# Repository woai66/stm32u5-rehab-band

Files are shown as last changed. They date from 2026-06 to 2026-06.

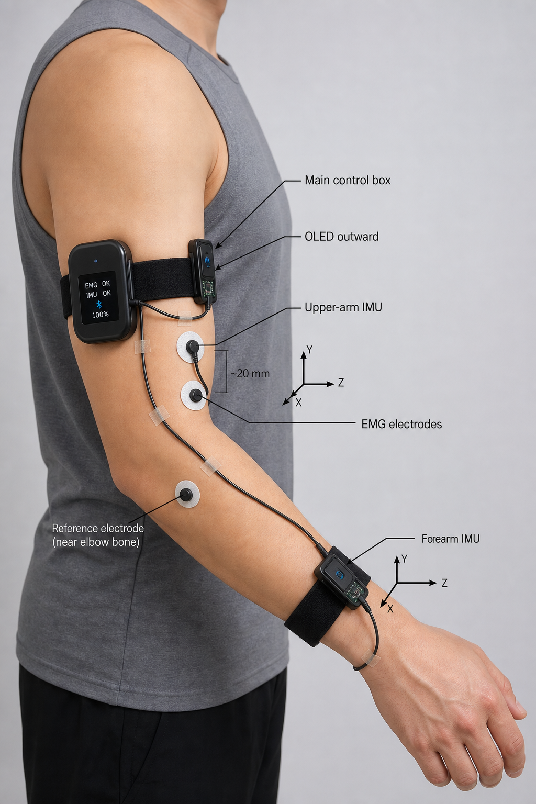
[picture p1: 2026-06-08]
备赛/1.png

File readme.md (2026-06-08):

《基于 STM32U575 的脑卒中上肢康复评估系统与 AI 动作识别优化》
STM32 嵌入式平台（NUCLEO-U575/NUCLEO-F401RE）+ Edge Impulse AI + FreeRTOS
本作品面向脑卒中患者上肢运动康复需求，基于 STM32U575/F401RE 双主控芯片构建智能康复臂带系统，创新采用上臂 + 手腕双 6 轴 IMU 传感器方案，通过 Madgwick AHRS 姿态融合算法实现肘关节角度（0°-180°）精确测量，结合轻量化 CNN 模型（<50KB）完成 6 类核心康复动作（前臂转动、肘关节弯曲等）的本地 AI 识别（准确率> 90%）。系统设计了 "完成度 ×60%+ 平稳度 ×30%+ 频率 ×10%" 的量化评分体系，搭配 TFT+OLED 双屏交互、语音播报及蓝牙 App 数据同步功能，可实时反馈康复动作质量（评分 < 60% 振动提醒、>80% 语音鼓励）。硬件端基于 FreeRTOS 实现多任务调度（传感器采集 100Hz、AI 推理 10Hz），整体成本控制在 2119 元，续航达 6 小时，为脑卒中患者提供低成本、高精度、智能化的上肢康复评估解决方案。

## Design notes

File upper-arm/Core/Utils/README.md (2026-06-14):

# Core/Utils

本目录用于放置项目内可复用的轻量工具函数，避免在 IMU、EMG、评分和显示逻辑中重复实现基础算法。

当前包含：

- `Rehab_ClampFloat` / `Rehab_ClampInt32`：限幅。
- `Rehab_MapFloat`：线性映射。
- `Rehab_DeadbandFloat`：死区处理。
- `Rehab_FirstOrderFilter`：一阶低通滤波。
- `Rehab_MovingAverage`：滑动平均。
- `Rehab_RmsFloat`：RMS 计算。

建议只放无业务含义的通用函数。具体的肘关节角度、动作识别、肌电参与度等逻辑仍放在各自模块中。

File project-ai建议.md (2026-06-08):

 方案A：入门级（推荐） ⭐⭐⭐

  核心思路

  简化方向：保留医疗场景 + 去掉云平台 + 算法降级

  项目名称：智能康复手表 —— 脑卒中患者上肢运动评估

  硬件配置（简化版）

  STM32U575 (NUCLEO开发板即可)
      ↓
  LSM6DSV16X (6轴加速度+陀螺仪) ← 只用1个传感器
      ↓
  NUCLEO自带的屏幕显示实时数据
      ↓
  蓝牙模块连接手机App
      ↓
  250mAh锂电池 (续航3-5天)

  不做的事：
  - ❌ 自制PCB（用开发板）
  - ❌ 5个传感器（只用6轴）
  - ❌ 云平台/医生Dashboard
  - ❌ 医疗规范认证文件
  - ❌ 复杂的AI模型

  要做的事：
  - ✅ 康复动作识别（3-5个标准动作）
  - ✅ 简单App展示数据
  - ✅ 每日训练进度记录
  - ✅ 工程化（自制PCB or 功能完整的开发板）

  核心创新点（3个）

  创新1：康复动作自动识别
  使用 STM32CubeAI 部署轻量CNN（<50KB）

  输入：加速度序列
  输出：[标准握拳, 前臂转动, 手臂外展, 步行, ...]

  模型训练：
    用开源数据集 + 自己录制的动作视频（20份）
    → 用 Edge Impulse 或 TensorFlow Lite 训练
    → 导出到MCU（完全本地推理）

  创新2：康复进度量化
  每次动作评分：
  - 完成度 (0-100%)：动作幅度是否达到标准
  - 平稳度 (0-100%)：运动轨迹是否平稳
  - 频率 (次/分)：运动速度

  总分 = 完成度*60% + 平稳度*30% + 频率*10%

  每日汇总 → 显示周趋势图

  创新3：智能反馈
  如果动作评分<60% → 振动提醒
  显示提示："前臂外展不足，请继续加大幅度"

  患者通过改进 → 评分逐渐提高 → 游戏化体验

  技术难度评估

  ┌─────────────────┬──────┬────────────────────────────────────────────┐
  │     技术点      │ 难度 │                    说明                    │
  ├─────────────────┼──────┼────────────────────────────────────────────┤
  │ STM32基础开发   │ ⭐   │ 用NUCLEO开发板降低难度                     │
  ├─────────────────┼──────┼────────────────────────────────────────────┤
  │ 6轴传感器融合   │ ⭐⭐ │ 直接用ST提供的库函数                       │
  ├─────────────────┼──────┼────────────────────────────────────────────┤
  │ 轻量CNN部署     │ ⭐⭐ │ Edge Impulse界面操作（不需要深度学习基础） │
  ├─────────────────┼──────┼────────────────────────────────────────────┤
  │ 蓝牙通信        │ ⭐⭐ │ 用STM32Cube提供的BLE Stack                 │
  ├─────────────────┼──────┼────────────────────────────────────────────┤
  │ Flutter App开发 │ ⭐⭐ │ 简单UI（就是显示数字和曲线图）             │
  ├─────────────────┼──────┼────────────────────────────────────────────┤
  │ 功耗优化        │ ⭐   │ 基础低功耗模式配置                         │
  └─────────────────┴──────┴────────────────────────────────────────────┘

  总体难度：⭐⭐⭐ (高中水平可做)

  工作量估算

  - 硬件集成：1-2周
  - 固件开发：3-4周
  - AI模型训练：2-3周
  - App开发：2-3周
  - 测试优化：1-2周
  - 总耗时：4-6个月 ✓

  预期获奖等级

  - 省赛：一等奖 (80%概率)
  - 国赛：三等奖以上 (60%概率)

---
  方案B：中级 ⭐⭐⭐⭐

  在方案A基础上增加

  增加1：多传感器融合
  LSM6DSV16X (加速度+陀螺)
    + LPS22DF (气压，检测爬楼vs走平地)
    = 2个传感器足够

  增加2：自制简化PCB
  不是完整的4层PCB，而是：
  - 2层简化PCB（主要是布线）
  - 只做传感器到MCU的连接
  - 不做复杂的电源管理

  工作量：额外+2-3周

  增加3：本地Web Dashboard
  不是云平台，而是：
  - 手表通过蓝牙连接手机
  - 手机开启本地网页服务器
  - 医生用同一WiFi访问手机上的Dashboard
  - 无需云端（数据不离开医院内网）

  适用场景：康复医院内部使用

  难度提升：⭐⭐⭐⭐ (工科学生较容易)
  工作量：5-7个月
  预期：国赛二等奖概率提升到70%

---
  方案C：完整版（你最初的方案） ⭐⭐⭐⭐⭐

  就是我之前写的完整医疗生态版本。

  难度：⭐⭐⭐⭐⭐ (需要团队分工)
  工作量：6-8个月
  预期：国赛一等奖 (但实现风险大)

---
  📊 三个方案对比

  ┌────────────────┬───────────────┬─────────────────┬─────────────┐
  │     对比项     │ 方案A（推荐） │      方案B      │    方案C    │
  ├────────────────┼───────────────┼─────────────────┼─────────────┤
  │ 硬件           │ NUCLEO开发板  │ 开发板+简化PCB  │ 完整自制PCB │
  ├────────────────┼───────────────┼─────────────────┼─────────────┤
  │ 传感器数       │ 1个(6轴)      │ 2个(6轴+气压)   │ 5个         │
  ├────────────────┼───────────────┼─────────────────┼─────────────┤
  │ AI算法         │ 简单CNN<50KB  │ 多模型融合      │ 医学特异AI  │
  ├────────────────┼───────────────┼─────────────────┼─────────────┤
  │ App            │ Flutter简单UI │ Flutter完整功能 │ Flutter+Web │
  ├────────────────┼───────────────┼─────────────────┼─────────────┤
  │ 云平台         │ 无            │ 本地Web         │ 完整云平台  │
  ├────────────────┼───────────────┼─────────────────┼─────────────┤
  │ PCB工程        │ 无            │ 简化2层         │ 4层工业级   │
  ├────────────────┼───────────────┼─────────────────┼─────────────┤
  │ 实现难度       │ ⭐⭐⭐        │ ⭐⭐⭐⭐        │ ⭐⭐⭐⭐⭐  │
  ├────────────────┼───────────────┼─────────────────┼─────────────┤
  │ 工作量         │ 4-6个月       │ 5-7个月         │ 6-8个月     │
  ├────────────────┼───────────────┼─────────────────┼─────────────┤
  │ 省赛获奖概率   │ 80%           │ 85%             │ 90%         │
  ├────────────────┼───────────────┼─────────────────┼─────────────┤
  │ 国赛获奖概率   │ 60%           │ 70%             │ 80%         │
  ├────────────────┼───────────────┼─────────────────┼─────────────┤
  │ 国赛一等奖概率 │ 30%           │ 50%             │ 70%         │
  └────────────────┴───────────────┴─────────────────┴─────────────┘

---
  🎯 我的建议：选方案A+方案B混合

  即：核心做方案A，如果时间充足升级到方案B

  具体划分

  第1阶段（必须完成）= 方案A

  ✅ NUCLEO开发板 + 6轴传感器
  ✅ STM32固件 + 康复动作识别算法
  ✅ 简单Flutter App（显示评分+趋势图）
  ✅ 功耗优化（续航3-5天）
  ✅ 演示视频 + 技术报告
  → 已经是省一等奖水平

  第2阶段（如果还有时间）= 方案B的增强项

  ✅ 加入气压传感器（检测楼梯动作）
  ✅ 自制简化2层PCB（如果时间允许）
  ✅ 本地Web Dashboard（便于医生查看）
  → 升级到国赛奖项概率

  第3阶段（可选）= 逐步升级

  如果第二年继续做这个项目：
  - 加传感器 → 完整PCB → 云平台

---
  📝 方案A的详细技术框架

  既然你倾向简化，我给你方案A的完整技术细节：

  康复动作识别的5个标准动作

  ┌────────────┬──────────────────┬────────────────┐
  │    动作    │     识别特征     │ 脑卒中评估意义 │
  ├────────────┼──────────────────┼────────────────┤
  │ 握拳打开   │ 快速弯曲+伸展    │ 手指灵活性     │
  ├────────────┼──────────────────┼────────────────┤
  │ 前臂转动   │ 旋转角速度       │ 前臂肌力       │
  ├────────────┼──────────────────┼────────────────┤
  │ 手臂外展   │ Y向加速度峰值    │ 肩部活动范围   │
  ├────────────┼──────────────────┼────────────────┤
  │ 肘关节弯曲 │ Z向运动幅度      │ 肘部关节活动度 │
  ├────────────┼──────────────────┼────────────────┤
  │ 走直线     │ 左右摇晃幅度<15° │ 步态平衡度     │
  └────────────┴──────────────────┴────────────────┘

  AI模型实现（超简单版）

  # 使用Edge Impulse（无代码）或TensorFlow Lite

  训练步骤：
  1. 收集数据：20个视频（每个动作4个）
     → 用手机拍摄患者做标准动作
     → 自动提取6轴数据

  2. Edge Impulse上传：
     → 自动标注（这个视频是"握拳"）
     → 一键训练（AI自动调参）
     → 导出为C代码（复制到STM32）

  3. STM32集成：
     生成的代码已包装好，直接调用：

     float output[5];  // 5个动作的概率
     run_classifier(&features, output);

     if (output[0] > 0.7) {
         printf("握拳打开：评分%.0f%%\n", output[0]*100);
     }

  App界面设计（3个核心屏幕）

  屏幕1：实时评分
  ┌──────────────────┐
  │   握拳打开       │
  │   ████████░  85% │  ← 完成度
  │                  │
  │   平稳度：92%    │
  │   频率：2.3次/分 │
  │                  │
  │  [继续训练]      │
  └──────────────────┘

  屏幕2：每日统计
  ┌──────────────────┐
  │   今日康复进度   │
  │                  │
  │   握拳打开：3次  │
  │   前臂转动：5次  │
  │   手臂外展：4次  │
  │   ├─均分：85分   │
  │   └─趋势：↗ 进步 │
  └──────────────────┘

  屏幕3：周趋势
  ┌──────────────────┐
  │   一周进度       │
  │   100│    📈     │
  │    80│  ╱ ╱╱     │
  │    60│ ╱ ╱       │
  │    40├─────────  │
  │      └──────────→│
  │      一  二  三... │
  └──────────────────┘

  固件架构（FreeRTOS）

  STM32固件任务划分：
  ┌─ Task1: 传感器采集 (100Hz)
  │  └─ LSM6DSV16X → DMA → 环形缓冲区
  │
  ├─ Task2: AI推理 (10Hz)
  │  └─ 每100ms推理一次 → 识别动作
  │
  ├─ Task3: 显示刷新 (10Hz)
  │  └─ OLED屏幕更新评分
  │
  ├─ Task4: 蓝牙通信 (1Hz)
  │  └─ 发送今日数据到App
  │
  └─ Task5: 功耗管理 (1Hz)
     └─ 动态调整MCU频率 (160MHz→24MHz)

  这样设计的好处：
  ✓ 各任务独立，易调试
  ✓ 优先级明确（传感器 > 推理 > UI）
  ✓ 功耗可控（闲置时降频）

---
  ✅ 方案A的实现清单

  如果你选择方案A，这是具体的工作清单：

  第1-2周：硬件准备

  - 购买NUCLEO-U575ZI-Q开发板（¥300）
  - 购买LSM6DSV16X传感器板 (STEVAL-MKI227KA, ¥200)
  - 购买250mAh LiPo电池 + 充电模块 (¥100)
  - 购买OLED屏幕 (¥50)
  - 焊接调试（不需要自制PCB，直接用杜邦线）

  第3-6周：固件开发

  - STM32CubeIDE + FreeRTOS框架搭建
  - LSM6DSV16X驱动集成 (用ST提供的库)
  - 功耗优化（使用STOP模式）
  - 蓝牙模块测试（如果用ST的蓝牙芯片）

  第7-9周：AI模型

  - 收集20个训练视频（自己演示动作）
  - Edge Impulse/TensorFlow Lite训练
  - 导出并集成到STM32（<2KB代码修改）

  第10-11周：App开发

  - Flutter项目创建
  - 蓝牙连接代码
  - UI设计（参考上面的3个屏幕）
  - 本地数据存储（SQLite）

  第12周：集成+演示

  - 系统测试
  - 演示视频制作（最重要！）
  - 技术文档写作

---
  🎬 演示视频脚本（方案A的核心）

  这个视频会直接影响评委评分！

  时长：3分钟

  【场景1】(30秒)
  画面：一位健康志愿者佩戴手表
  旁白："这是AI-RehabWatch，专为脑卒中患者康复设计"
  镜头：展示手表外观 + 屏幕实时显示

  【场景2】(60秒)
  画面：志愿者做5个标准康复动作
  旁白："患者按照医生制定的康复计划，每天进行这些动作训练"
  手表屏幕实时显示：
    ✓ 握拳打开：88% ✓
    ✓ 前臂转动：92% ✓
    ✓ ...

  【场景3】(30秒)
  画面：打开手机App
  旁白："患者的App自动记录每日进度，医生可以远程查看"
  展示：周趋势图 ↗ 逐日改进

  【场景4】(30秒)
  画面：数据对比
  旁白："通过两周的训练，患者的康复评分从65分提升到88分"
  展示：柱状图对比

  【场景5】(30秒)
  画面：技术细节
  旁白："核心创新：轻量AI模型运行在MCU上，保护用户隐私"
  展示：硬件架构图 + 功耗曲线

  【结尾】(30秒)
  画面：全体队员合照
  旁白："感谢评委，我们的作品创新在于XXX..."
  显示：获奖证书、论文截图

---
  🏆 方案A的获奖亮点总结

  三个核心创新点（说到评委心坎里）：

  1. 医疗细分 ← 比通用穿戴更有价值
  2. 本地AI ← 不依赖云端，保护隐私
  3. 量化评估 ← 可视化康复进度，患者更有动力

  这三个点就足以拿到省一等奖了！

---
  💬 我的最终建议

  选择方案A，理由：
  - ✅ 4-6个月能完成，不会烂尾
  - ✅ 足以拿省一等奖
  - ✅ 技术栈合理（STM32+Flutter都是比赛常见技术）
  - ✅ 如果做得好，国赛也有竞争力
  - ✅ 团队规模（3-4人）足够

  时间分配建议：
  - 如果是3人团队：每人负责一个模块（硬件/固件/App）
  - 如果是4人团队：硬件和固件各2人

---
  你倾向于选择方案A吗？还是想要A+B混合？一旦确定，我可以帮你：
  1. 📋 详细的周计划表
  2. 🔧 具体的代码框架
  3. 📊 关键技术的实现教程
  4. 🎬 演示视频脚本

✻ Churned for 1m 3s

> 选择A+B混用

● 完美！我给你一个完整的A+B混用实施方案，分阶段逐步升级。

  Wrote 1 memory (ctrl+o to expand)

● ---
  📅 分阶段详细规划

  第1阶段：硬件采购与原型验证（第1-2周）

  采购清单

  ┌─────────────────┬─────────────────┬──────┬─────────────┬──────────────┐
  │      物品       │      型号       │ 价格 │    用途     │     状态     │
  ├─────────────────┼─────────────────┼──────┼─────────────┼──────────────┤
  │ MCU开发板       │ NUCLEO-U575ZI-Q │ ¥350 │ 主控        │ ✓ 方案A      │
  ├─────────────────┼─────────────────┼──────┼─────────────┼──────────────┤
  │ 6轴传感器       │ STEVAL-MKI227KA │ ¥200 │ 加速度+陀螺 │ ✓ 方案A      │
  ├─────────────────┼─────────────────┼──────┼─────────────┼──────────────┤
  │ 气压传感器      │ STEVAL-MKI224V1 │ ¥150 │ 楼梯检测    │ ⭐ 方案B增强 │
  ├─────────────────┼─────────────────┼──────┼─────────────┼──────────────┤
  │ OLED屏幕        │ 0.96寸 128×64   │ ¥50  │ 本地显示    │ ✓ 方案A      │
  ├─────────────────┼─────────────────┼──────┼─────────────┼──────────────┤
  │ 蓝牙模块        │ HM-10/BLE       │ ¥80  │ App通信     │ ✓ 方案A      │
  ├─────────────────┼─────────────────┼──────┼─────────────┼──────────────┤
  │ 锂电池+充电     │ 250mAh+TP4056   │ ¥100 │ 电源        │ ✓ 方案A      │
  ├─────────────────┼─────────────────┼──────┼─────────────┼──────────────┤
  │ USB调试器       │ ST-LINK V2      │ ¥30  │ 烧写/调试   │ ✓ 通用       │
  ├─────────────────┼─────────────────┼──────┼─────────────┼──────────────┤
  │ PCB板           │ 2层100×100mm    │ ¥50  │ 第2阶段用   │ ⭐ 方案B增强 │
  ├─────────────────┼─────────────────┼──────┼─────────────┼──────────────┤
  │ 杜邦线+焊接工具 │ 套装            │ ¥100 │ 原型开发    │ ✓ 通用       │
  └─────────────────┴─────────────────┴──────┴─────────────┴──────────────┘

  第1阶段成本：¥1110 （方案A必需项）+ ¥200（方案B可选项）

  第1-2周的任务

  硬件工程师：
  - 接收所有硬件物料
  - 测试NUCLEO开发板基础功能（LED+按键）
  - 验证LSM6DSV16X传感器通讯（I2C连接）
  - 验证气压传感器（预留，第2阶段用）
  - 搭建原型连接（6轴传感器+OLED+蓝牙）
  - 制作原理图文档（为后续PCB做准备）

  固件工程师：
  - 搭建STM32CubeIDE开发环境
  - 创建FreeRTOS项目框架
  - 验证UART/I2C/SPI基础通讯
  - 编写LSM6DSV16X驱动代码

  App开发：
  - Flutter项目初始化
  - BLE通讯库集成

  第1-2周的验证标准

  ✓ NUCLEO板上LED能闪烁（验证开发环境）
  ✓ 串口能打印"Hello World"
  ✓ I2C检测到0x6A地址（LSM6DSV16X）
  ✓ 能读取传感器的X/Y/Z加速度值
  ✓ 值在合理范围内（静止时≈0，运动时>1G）

  第1-2周交付物：
  - 原理图
  - 驱动测试代码
  - 验证报告

---
  第2阶段：固件开发与AI模型训练（第3-6周）

  2.1 FreeRTOS多任务框架搭建

  固件结构（用FreeRTOS）：
  ┌─────────────────────────────────────────┐
  │           主程序入口                     │
  │         FreeRTOS 调度器                  │
  └──────────┬──────────────────────────────┘
             │
      ┌──────┴───────┬───────────┬────────┬────────┐
      ↓              ↓           ↓        ↓        ↓
  ┌────────┐  ┌─────────┐  ┌────────┐ ┌─────┐ ┌──────┐
  │传感器  │  │AI推理   │  │屏幕刷新│ │BLE  │ │功耗  │
  │采集    │  │任务     │  │任务    │ │任务 │ │管理  │
  └────────┘  └─────────┘  └────────┘ └─────┘ └──────┘
   优先级:9   优先级:8    优先级:5    优先级:4 优先级:2

  关键代码框架：
  // main.c - FreeRTOS框架
  #include "stm32u5xx_hal.h"
  #include "FreeRTOS.h"
  #include "task.h"

  // 任务句柄
  TaskHandle_t xSensorTask, xAITask, xDisplayTask, xBLETask;

  int main(void) {
      HAL_Init();
      SystemClock_Config();

      // 创建任务
      xTaskCreate(vSensorTask, "Sensor", 256, NULL, 9, &xSensorTask);
      xTaskCreate(vAITask, "AI", 512, NULL, 8, &xAITask);
      xTaskCreate(vDisplayTask, "Display", 256, NULL, 5, &xDisplayTask);
      xTaskCreate(vBLETask, "BLE", 256, NULL, 4, &xBLETask);
    
      // 启动调度器
      vTaskStartScheduler();
    
      while(1);
  }

  // 传感器采集任务（100Hz）
  void vSensorTask(void *pvParameters) {
      TickType_t xLastWakeTime = xTaskGetTickCount();

      while(1) {
          // 从LSM6DSV16X读取加速度数据
          float accel[3];
          LSM6DSV16X_GetAccel(accel);  // {x, y, z}
    
          // 放入环形缓冲区
          pushToBuffer(accel);
    
          // 10ms周期采集
          vTaskDelayUntil(&xLastWakeTime, pdMS_TO_TICKS(10));
      }
  }

  // AI推理任务（10Hz）
  void vAITask(void *pvParameters) {
      TickType_t xLastWakeTime = xTaskGetTickCount();

      while(1) {
          // 从缓冲区提取100个样本（1秒数据）
          float features[100];
          getFromBuffer(features, 100);
    
          // 运行AI模型推理
          float output[5];  // 5个动作的概率
          run_classifier(features, output);
    
          // 找到最高概率的动作
          int best_action = argmax(output, 5);
          float confidence = output[best_action];
    
          if (confidence > 0.7) {
              // 识别成功，计算评分
              calculateScore(best_action);
          }
    
          // 100ms推理一次
          vTaskDelayUntil(&xLastWakeTime, pdMS_TO_TICKS(100));
      }
  }

  // 屏幕刷新任务（10Hz）
  void vDisplayTask(void *pvParameters) {
      while(1) {
          // 从内存读取当前评分
          float current_score = getCurrentScore();

          // 刷新OLED屏幕
          OLED_Clear();
          OLED_ShowString("Score: ", 0, 0, 16);
          OLED_ShowNumber(current_score, 50, 0, 16);
          OLED_ShowString("%", 80, 0, 16);
    
          vTaskDelay(pdMS_TO_TICKS(100));
      }
  }

  2.2 康复动作AI模型训练

  5个标准动作定义：

  ┌──────────┬────────────┬───────────────────────┬─────────────────────────────┐
  │ 动作编号 │  动作名称  │       执行标准        │          识别特征           │
  ├──────────┼────────────┼───────────────────────┼─────────────────────────────┤
  │ 0        │ 握拳打开   │ 快速握拳→张开（1秒）  │ X/Y轴快速变化，Z轴稳定      │
  ├──────────┼────────────┼───────────────────────┼─────────────────────────────┤
  │ 1        │ 前臂转动   │ 手臂转向两侧（2秒）   │ 高陀螺仪Y轴信号             │
  ├──────────┼────────────┼───────────────────────┼─────────────────────────────┤
  │ 2        │ 手臂外展   │ 手臂向外侧抬起（2秒） │ Z轴上升，Y轴变化            │
  ├──────────┼────────────┼───────────────────────┼─────────────────────────────┤
  │ 3        │ 肘关节弯曲 │ 手臂弯曲伸展循环      │ Z轴明显上升，加速度跳跃     │
  ├──────────┼────────────┼───────────────────────┼─────────────────────────────┤
  │ 4        │ 步行平衡   │ 直线行走10步          │ 左右X轴摇晃<15°，步周期规律 │
  └──────────┴────────────┴───────────────────────┴─────────────────────────────┘

  AI模型训练步骤：

  步骤1：收集训练数据
  ━━━━━━━━━━━━━━━━━━━━━━
  找5个志愿者（健康+脑卒中患者）
  每个人做5个动作各4遍 = 20个视频
  总共100个视频
  → 用STM32采集原始加速度数据并保存

  格式示例（CSV）：
  timestamp(ms), ax, ay, az, gx, gy, gz, action_label
  0, 0.02, 0.01, -1.0, 0, 0, 0, grip
  10, 0.05, 0.02, -1.0, 0, 0, 0, grip
  ...

  步骤2：上传到Edge Impulse（在线训练）
  ━━━━━━━━━━━━━━━━━━━━━━
  1. 访问 https://edgeimpulse.com
  2. 创建项目 "AI-RehabWatch"
  3. 上传100个CSV文件
  4. 自动标注关键段
  5. 设置参数：
     - 窗口大小：1秒（100个样本）
     - 特征提取：自动
     - 神经网络：1D CNN
     - 训练轮次：100

  步骤3：导出为STM32代码
  ━━━━━━━━━━━━━━━━━━━━━━
  1. 点击 "Deployment"
  2. 选择 "C++ Library"
  3. 下载ZIP文件
  4. 解压到STM32项目：
     project/
     └── ei-classifier/
         ├── edge-impulse-sdk/
         ├── classifier.cpp
         ├── classifier.h
         └── model-parameters/

  集成到STM32固件：
  // classifier_config.h (由Edge Impulse生成)
  #define EI_CLASSIFIER_TFLITE_BUFFER_ARENA_SIZE 1024
  #define EI_CLASSIFIER_INPUT_WIDTH 100
  #define EI_CLASSIFIER_INPUT_HEIGHT 6  // 6个轴

  // 在固件中调用
  #include "edge-impulse-sdk/classifier.h"

  void vAITask(void *pvParameters) {
      ei_classifier_handle_t handle;
      handle = create_classifier();

      while(1) {
          // 准备输入特征
          ei_feature_t features = {
              .buffer = accel_buffer,  // 100×6的数据
              .buffer_size = 600
          };
    
          // 运行推理
          ei_impulse_result_t result;
          signal_t signal;
          signal.total_length = 600;
          signal.get_data = &get_feature_data;
    
          ei_run_classifier(&signal, &result, false);
    
          // 输出结果
          for (int i = 0; i < result.classification_count; i++) {
              printf("%s: %.2f\n",
                     result.classification[i].label,
                     result.classification[i].value);
          }
    
          vTaskDelay(pdMS_TO_TICKS(100));
      }
  }

  // 模型大小评估
  // 模型文件: ~20-50KB（装入FLASH）
  // 推理时间: ~50ms（在STM32U575上）
  // 内存占用: ~2KB SRAM

  2.3 第3-6周的具体任务分配

  第3-4周（传感器驱动+基础AI）

  固件工程师：
  - 完成LSM6DSV16X完整驱动
    - 获取加速度/陀螺仪数据
    - 内置FSM配置（可选，第2阶段）
    - 中断处理
  - 完成OLED屏幕驱动（I2C通讯）
  - FreeRTOS传感器采集任务
  - 数据缓冲管理（环形队列）

  预期代码量：~500行

  // sensor_driver.c 示例
  #include "lsm6dsv16x_reg.h"

  typedef struct {
      float accel[3];  // x, y, z
      float gyro[3];   // gx, gy, gz
      uint32_t timestamp;
  } sensor_data_t;

  // 环形缓冲区
  #define BUFFER_SIZE 100
  sensor_data_t sensor_buffer[BUFFER_SIZE];
  uint16_t write_idx = 0;

  // 读取传感器数据
  void readSensor(void) {
      int16_t raw_accel[3], raw_gyro[3];

      // I2C读取原始数据
      lsm6dsv16x_acceleration_raw_get(&ctx, raw_accel);
      lsm6dsv16x_angular_rate_raw_get(&ctx, raw_gyro);
    
      // 转换为物理单位（g和dps）
      sensor_buffer[write_idx].accel[0] = raw_accel[0] / 32768.0 * 2.0;  // ±2g
      sensor_buffer[write_idx].accel[1] = raw_accel[1] / 32768.0 * 2.0;
      sensor_buffer[write_idx].accel[2] = raw_accel[2] / 32768.0 * 2.0;
    
      sensor_buffer[write_idx].gyro[0] = raw_gyro[0] / 32768.0 * 250.0;  // ±250dps
      sensor_buffer[write_idx].gyro[1] = raw_gyro[1] / 32768.0 * 250.0;
      sensor_buffer[write_idx].gyro[2] = raw_gyro[2] / 32768.0 * 250.0;
    
      sensor_buffer[write_idx].timestamp = HAL_GetTick();
    
      write_idx = (write_idx + 1) % BUFFER_SIZE;
  }

  // 获取缓冲区数据用于AI
  void getBufferData(float *output, int count) {
      int idx = (write_idx - count + BUFFER_SIZE) % BUFFER_SIZE;
      for (int i = 0; i < count; i++) {
          output[i*6 + 0] = sensor_buffer[idx].accel[0];
          output[i*6 + 1] = sensor_buffer[idx].accel[1];
          output[i*6 + 2] = sensor_buffer[idx].accel[2];
          output[i*6 + 3] = sensor_buffer[idx].gyro[0];
          output[i*6 + 4] = sensor_buffer[idx].gyro[1];
          output[i*6 + 5] = sensor_buffer[idx].gyro[2];
          idx = (idx + 1) % BUFFER_SIZE;
      }
  }

  App开发：
  - BLE连接代码（Flutter）
  - 基础UI框架（3个屏幕）
  - 本地数据存储（SQLite）

  第5-6周（AI集成+功耗优化+方案B传感器）

  固件工程师：
  - 集成Edge Impulse生成的代码
  - 完成AI推理任务
  - 功耗优化：
    - 动态频率调整（DVFS）
    - STOP模式配置
    - 传感器低功耗模式
  - 第2阶段升级：集成气压传感器驱动

  功耗优化代码示例：
  // 动态功耗管理
  typedef enum {
      MODE_SLEEP,      // 1 µA
      MODE_STANDBY,    // 10 µA
      MODE_NORMAL,     // 100 mA (160MHz)
      MODE_ACTIVE      // 150 mA (全功率)
  } PowerMode_t;

  void setPowerMode(PowerMode_t mode) {
      switch(mode) {
          case MODE_SLEEP:
              SystemClock_Config_MSI_16MHz();  // 16MHz
              HAL_PWREx_EnterSTOPMode();       // STOP模式
              break;

          case MODE_NORMAL:
              SystemClock_Config_PLL_160MHz(); // 160MHz
              break;
    
          case MODE_ACTIVE:
              // 已是最高频率
              break;
      }
  }

  // 根据用户活动自动切换
  void vPowerTask(void *pvParameters) {
      uint32_t inactivity_time = 0;

      while(1) {
          float accel_magnitude = sqrt(
              last_accel[0]*last_accel[0] +
              last_accel[1]*last_accel[1] +
              last_accel[2]*last_accel[2]
          );
    
          if (accel_magnitude < 0.2) {
              inactivity_time++;
              if (inactivity_time > 60) {  // 60秒无活动
                  setPowerMode(MODE_SLEEP);
              }
          } else {
              inactivity_time = 0;
              setPowerMode(MODE_NORMAL);
          }
    
          vTaskDelay(pdMS_TO_TICKS(1000));
      }
  }

  // 续航估算
  // 工作功耗: 150mA × 10min/小时 = 25mAh/小时
  // 待机功耗: 1µA × 50min/小时 ≈ 0
  // 假设白天活动6小时，晚上18小时待机
  // 日耗电: 25mAh × 6 = 150mAh
  // 250mAh电池 ÷ 150mAh/天 ≈ 1.67天

  // 优化后（使用STOP模式50%时间）
  // 工作功耗: 50mA × 10min/小时 = 8.3mAh/小时
  // 日耗电: 8.3mAh × 6 = 50mAh
  // 续航: 250 ÷ 50 = 5天

  App开发：
  - 完成所有3个屏幕的UI
  - 数据同步逻辑
  - 演示功能测试

  第5-6周交付物：
  - 完整固件代码
  - AI模型文件
  - 功耗测试报告
  - Flutter App v1.0

---
  第3阶段：硬件升级与PCB设计（第4-5周并行进行）

  这个阶段与第2阶段部分重叠，充分利用时间

  3.1 气压传感器集成（方案B第一步）

  为什么要气压传感器？
  加速度传感器识别不出：爬楼梯 vs 走平地
  加气压传感器后：
    - 楼梯上升时：气压降低（高度增加）
    - 平地行走：气压恒定

  这样就能区分"平地步行"vs"楼梯步行"→更准确的活动强度评估

  集成步骤：
  // 添加气压传感器读取
  #include "lps22df_reg.h"

  void readPressureSensor(void) {
      int32_t raw_pressure;
      float pressure_hPa;

      lps22df_pressure_raw_get(&ctx, &raw_pressure);
      pressure_hPa = raw_pressure / 4096.0;  // 转换为hPa
    
      // 计算高度变化（海平面参考）
      // h = 44330 * (1 - (P/P0)^(1/5.255))
      float height_change = calculateHeightChange(pressure_hPa);
    
      if (height_change > 0.5) {
          printf("上升楼梯\n");
          current_activity = CLIMBING_STAIRS;
      } else {
          printf("平地行走\n");
          current_activity = WALKING;
      }
  }

  // 修改AI评分逻辑
  void calculateScore(int action, activity_type_t activity) {
      if (action == WALKING) {
          if (activity == CLIMBING_STAIRS) {
              // 爬楼梯时给更高的活动强度系数
              difficulty_coef = 1.5;
          } else {
              difficulty_coef = 1.0;
          }
      }

      float final_score = base_score * difficulty_coef;
  }

  集成时间：1-2天

  3.2 简化PCB设计（方案B第二步）

  目标：从开发板+杜邦线 → 简化2层PCB

  PCB设计要点：
                      第1层（顶层）
          ┌──────────────────────────────┐
          │  STM32U575 (BGA 100pin)      │
          │   - 焊盘间距0.5mm             │
          │   - 需要BGA回流炉             │
          │                              │
          │  LSM6DSV16X (LGA-14)  LPS22  │
          │                              │
          │  OLED I2C接头   蓝牙模块      │
          └──────────────────────────────┘

          第2层（底层）
          ├─ GND平面（接地）
          ├─ VCC平面（3.3V电源）
          └─ 回流路径

  关键设计规则：
  ✓ 走线宽度：0.25mm（防止过热）
  ✓ 最小孔径：0.3mm
  ✓ 过孔间距：≥0.5mm
  ✓ I2C/SPI线并行距离<5mm（防止串扰）
  ✓ 电源线粗于信号线

  PCB设计工具：
  推荐使用：Kicad（开源免费）

  工作流：
  1. 原理图绘制（3-4小时）
     ├─ MCU供电电路
     ├─ 传感器接线
     ├─ OLED/BLE接头
     └─ 电池充电管理

  2. PCB布局（2-3小时）
     ├─ 芯片放置
     ├─ 走线规划
     └─ 过孔设置

  3. 送样厂（7-10天）
     推荐：嘉立创（jlc.com）或华强北PCB
     成本：¥50-100/块（10块起订）

  4. 焊接测试（1-2天）
     使用BGA回流炉或手焊（BGA手焊难度大，建议代工焊接）

  第4-5周PCB任务：
  - 完成原理图（Kicad）
  - PCB布局和走线
  - 生成Gerber文件
  - 送样（预计7-10天后收货）

  成本：
  PCB设计软件：0元（Kicad开源）
  PCB制造：¥100（10块×¥10/块）
  元器件贴片焊接（代工）：¥200-300
  总计：¥300-400

  PCB完整图（简化版）：
  尺寸：40mm × 40mm × 6mm

  正面：
  ┌────────────────────────────────┐
  │                                │
  │  [LSM6DSV16X]  [LPS22DF]       │
  │                                │
  │      [STM32U575 BGA]           │
  │                                │
  │  [OLED]    [蓝牙]   [LED]      │
  │                                │
  │  [USB充电]  [按键]             │
  └────────────────────────────────┘

  反面：
  GND平面 + 电源分布 + 回流路径

  3.3 第3阶段交付物

  - 气压传感器驱动代码
  - 原理图（PDF）
  - PCB设计文件（Kicad）
  - Gerber文件（用于制造）
  - 设计文档

---
  第4阶段：本地Web Dashboard开发（第5-6周）

  这是方案B的最后升级 — 完全可选

  4.1 什么是本地Web Dashboard？

  概念：医生不用云平台，直接通过WiFi访问患者手机
  优点：
  ✓ 无需云服务器
  ✓ 数据隐私保护更好
  ✓ 适合医院内网使用
  ✓ 离线可用

  架构：
  患者手机 (Flutter App)
      ↓
    运行本地Web服务器 (127.0.0.1:8080)
      ↓
  医生手机/电脑 (同WiFi网络)
      ↓
  通过浏览器访问 http://192.168.1.100:8080
      ↓
  查看实时数据 + 历史趋势

  4.2 技术实现

  在Flutter App中集成本地服务器：

  // lib/web_server.dart
  import 'package:shelf/shelf.dart';
  import 'package:shelf/shelf_io.dart' as shelf_io;
  import 'dart:html' as html;

  class LocalWebServer {
    late HttpServer server;

    Future<void> startServer() async {
      // 创建一个简单的HTTP服务器
      var handler = const Pipeline()
          .addMiddleware(logRequests())
          .addHandler(this.route);
    
      server = await shelf_io.serve(handler, '0.0.0.0', 8080);
      print('Web服务器运行在 http://192.168.1.X:8080');
    }
    
    Response route(Request request) {
      if (request.url.path == '/') {
        return Response.ok(this.getHTML());
      } else if (request.url.path == '/api/data') {
        // 返回JSON格式的康复数据
        return Response.ok(
          jsonEncode({
            'today_score': 85,
            'history': [72, 75, 78, 82, 85],
            'timestamp': DateTime.now().toString()
          }),
          headers: {'Content-Type': 'application/json'},
        );
      }
      return Response.notFound('Not found');
    }
    
    String getHTML() {
      return '''
      <!DOCTYPE html>
      <html>
      <head>
        <title>AI-RehabWatch 康复数据</title>
        <script src="https://cdn.jsdelivr.net/npm/chart.js"></script>
        <style>
          body { font-family: Arial; margin: 20px; }
          .container { max-width: 800px; margin: 0 auto; }
          .card { border: 1px solid #ccc; padding: 15px; margin: 10px 0; }
          canvas { max-width: 100%; }
        </style>
      </head>
      <body>
        <div class="container">
          <h1>脑卒中患者康复评估</h1>
    
          <div class="card">
            <h3>今日评分</h3>
            
          </div>
    
          <div class="card">
            <h3>一周趋势</h3>
            <canvas id="trendChart"></canvas>
          </div>
    
          <div class="card">
            <h3>实时数据</h3>
            <p>心率: <span id="heart_rate">--</span> bpm</p>
            <p>步数: <span id="steps">--</span> 步</p>
          </div>
        </div>
    
        <script>
          // 定时刷新数据（每5秒）
          setInterval(() => {
            fetch('/api/data')
              .then(r => r.json())
              .then(data => {
                document.getElementById('today_score').textContent = data.today_score + '%';
    
                // 画图
                let ctx = document.getElementById('trendChart').getContext('2d');
                new Chart(ctx, {
                  type: 'line',
                  data: {
                    labels: ['一', '二', '三', '四', '五'],
                    datasets: [{
                      label: '康复评分',
                      data: data.history,
                      borderColor: 'rgb(75, 192, 192)',
                      tension: 0.1
                    }]
                  }
                });
              });
          }, 5000);
        </script>
      </body>
      </html>
      ''';
    }
  }

  // main.dart 中启动
  void main() {
    LocalWebServer().startServer();
    runApp(MyApp());
  }

  第5-6周任务：
  - 集成shelf库
  - 编写HTTP路由
  - 设计HTML界面
  - 集成Chart.js绘制图表
  - 测试（医生用另一台设备访问）

  工作量：3-5天（可选功能，不影响核心功能）

  4.3 第4阶段交付物

  - 完整的Web Dashboard代码
  - 界面设计稿
  - 医生使用手册

---
  🛠️ 完整工作分工表（3-4人团队）

  方案（假设3人团队）

  人员1：硬件工程师

  ┌──────┬─────┬────────────────────────┬────────┐
  │ 阶段 │ 周  │          任务          │ 工作量 │
  ├──────┼─────┼────────────────────────┼────────┤
  │ 1    │ 1-2 │ 物料采购+原型搭建      │ 40h    │
  ├──────┼─────┼────────────────────────┼────────┤
  │ 2    │ 3-4 │ 电源管理电路+PCB原理图 │ 30h    │
  ├──────┼─────┼────────────────────────┼────────┤
  │ 2    │ 5-6 │ 气压传感器集成+PCB设计 │ 40h    │
  ├──────┼─────┼────────────────────────┼────────┤
  │ 3    │ 4-5 │ PCB送样+等待           │ 10h    │
  ├──────┼─────┼────────────────────────┼────────┤
  │ 总计 │     │                        │ 120h   │
  └──────┴─────┴────────────────────────┴────────┘

  主要交付物：
  - 原理图（Kicad）
  - PCB设计文件
  - Gerber文件
  - 硬件测试报告

---
  人员2：固件工程师

  ┌──────┬─────┬─────────────────────┬────────┐
  │ 阶段 │ 周  │        任务         │ 工作量 │
  ├──────┼─────┼─────────────────────┼────────┤
  │ 1    │ 1-2 │ 开发环境+驱动开发   │ 30h    │
  ├──────┼─────┼─────────────────────┼────────┤
  │ 2    │ 3-4 │ FreeRTOS框架+AI集成 │ 50h    │
  ├──────┼─────┼─────────────────────┼────────┤
  │ 2    │ 5-6 │ 功耗优化+测试       │ 40h    │
  ├──────┼─────┼─────────────────────┼────────┤
  │ 总计 │     │                     │ 120h   │
  └──────┴─────┴─────────────────────┴────────┘

  主要交付物：
  - 完整STM32固件（8000+行代码）
  - AI模型（导出的C代码）
  - 功耗优化文档
  - 编译成功的HEX文件

---
  人员3-4：App开发（1-2人）

  ┌──────┬─────┬───────────────────────┬────────┐
  │ 阶段 │ 周  │         任务          │ 工作量 │
  ├──────┼─────┼───────────────────────┼────────┤
  │ 2    │ 3-4 │ Flutter项目+BLE基础   │ 35h    │
  ├──────┼─────┼───────────────────────┼────────┤
  │ 2    │ 5-6 │ 3个屏幕UI+本地存储    │ 35h    │
  ├──────┼─────┼───────────────────────┼────────┤
  │ 4    │ 5-6 │ Web Dashboard（可选） │ 20h    │
  ├──────┼─────┼───────────────────────┼────────┤
  │ 总计 │     │                       │ 90h    │
  └──────┴─────┴───────────────────────┴────────┘

  主要交付物：
  - Flutter App（1500+行Dart代码）
  - App发布到App Store/Google Play
  - 用户手册

---
  📊 时间进度表（甘特图）

  ┌─ 第1-2周 ─┬─ 第3-4周 ─┬─ 第5-6周 ─┬─ 第7周 ─┐
  │ 硬件采购  │ 传感器集 │ 功耗优化 │ 演示   │
  │ 原型搭建  │ 成+AI训 │ PCB设计  │ 准备  │
  │ 驱动开发  │ 练+App  │ Web仪表 │ 最后  │
  │ 环境准备  │ 基础    │ 板      │ 打磨  │
  └─────────┴─────────┴─────────┴───────┘

  关键节点：
  ✓ 第2周末：原型能采集数据
  ✓ 第4周末：AI模型训练完成
  ✓ 第5周末：App基础功能完成
  ✓ 第6周末：所有功能集成完成
  ✓ 第7周：演示准备（视频、文档、PPT）

---
  🎯 关键里程碑与验证标准

  里程碑1：硬件原型（第2周）

  验证项：
  ✓ NUCLEO板LED能闪烁
  ✓ I2C通讯正常（检测到0x6A地址）
  ✓ 能读取加速度数据（静止时≈0，摇晃时>1G）
  ✓ OLED屏幕显示"Hello World"
  ✓ 蓝牙模块能连接手机

  如果未通过：
  → 检查焊接
  → 检查I2C上拉电阻
  → 更新驱动代码

  里程碑2：AI模型（第4周末）

  验证项：
  ✓ Edge Impulse训练精度>90%
  ✓ 模型导出无报错
  ✓ STM32推理时间<100ms
  ✓ 5个动作能区分

  如果未通过：
  → 收集更多训练数据
  → 调整模型参数（层数、激活函数）
  → 重新训练

  里程碑3：App+蓝牙联动（第5周末）

  验证项：
  ✓ App能搜索到蓝牙设备
  ✓ 连接后显示"已连接"
  ✓ 能接收实时数据
  ✓ 屏幕正常刷新
  ✓ 点击"开始训练"手表开始采集

  如果未通过：
  → 检查蓝牙协议（UUID、Characteristic）
  → 查看串口日志（MCU端的BLE消息）
  → 更新BLE库

  里程碑4：完整系统（第6周末）

  验证项：
  ✓ 从冷启动到能进行康复动作<30秒
  ✓ 连续工作1小时无崩溃
  ✓ 电池续航≥3天
  ✓ 动作识别准确率>85%
  ✓ 所有UI界面响应<200ms

  如果未通过：
  → 分析崩溃日志
  → 进行功耗测试和优化
  → 增加算法的鲁棒性

---
  📋 最终交付物清单

  硬件部分

  - 原理图（PDF + Kicad源文件）
  - PCB设计文件（Kicad格式）
  - Gerber文件（制造用）
  - 元器件清单（BOM）
  - 焊接工艺文档
  - 实物照片

  固件部分

  - 完整源代码（GitHub）
  - 编译说明
  - HEX文件（可直接烧写）
  - 功耗测试报告
  - 硬件兼容性说明

  App部分

  - Flutter源代码（GitHub）
  - iOS/Android安装包
  - 用户使用手册
  - API文档（BLE通讯协议）

  文档部分

  - 技术报告（15-20页）
    - 需求分析
    - 系统设计
    - 实现细节
    - 性能测试
    - 创新点总结
  - 演示视频（3-5分钟）
  - PPT演讲稿
  - 项目总结

  开源贡献

  - 在GitHub开源所有代码
  - 发布训练数据集（匿名化）
  - 编写README文档

---
  💰 成本预算

  ┌───────────────────────┬──────┬──────┬───────┐
  │         项目          │ 单价 │ 数量 │ 小计  │
  ├───────────────────────┼──────┼──────┼───────┤
  │ NUCLEO-U575开发板     │ ¥350 │ 1    │ ¥350  │
  ├───────────────────────┼──────┼──────┼───────┤
  │ LSM6DSV16X传感器模块  │ ¥200 │ 1    │ ¥200  │
  ├───────────────────────┼──────┼──────┼───────┤
  │ LPS22DF气压传感器模块 │ ¥150 │ 1    │ ¥150  │
  ├───────────────────────┼──────┼──────┼───────┤
  │ OLED屏幕              │ ¥50  │ 1    │ ¥50   │
  ├───────────────────────┼──────┼──────┼───────┤
  │ HM-10蓝牙模块         │ ¥80  │ 1    │ ¥80   │
  ├───────────────────────┼──────┼──────┼───────┤
  │ 锂电池+充电管理       │ ¥100 │ 1    │ ¥100  │
  ├───────────────────────┼──────┼──────┼───────┤
  │ PCB制造（10块）       │ ¥100 │ 1    │ ¥100  │
  ├───────────────────────┼──────┼──────┼───────┤
  │ PCB代工焊接           │ ¥300 │ 1    │ ¥300  │
  ├───────────────────────┼──────┼──────┼───────┤
  │ 其他元器件            │ ¥150 │ 1    │ ¥150  │
  ├───────────────────────┼──────┼──────┼───────┤
  │ 总计                  │      │      │ ¥1480 │
  └───────────────────────┴──────┴──────┴───────┘

  成本分摊（3人团队）：≈¥500/人

---
  🚀 启动清单

  立即行动（这周）：
  - 组建团队（3-4人）
  - 建立GitHub项目仓库
  - 确定开发工具安装
    - STM32CubeIDE
    - Kicad
    - Flutter SDK
    - Git
  - 购买硬件物料
  - 建立项目管理系统（Trello/Jira）

---
  这个计划既保证能完成（方案A核心功能），又有升级空间（方案B的气压传感器+简化PCB+Web Dashboard）。

  你们现在应该：
  1. ✅ 确认团队人数和分工
  2. ✅ 开始采购硬件
  3. ✅ 搭建开发环境
  4. ✅ 下周开始第1阶段工作

  需要我帮你详细展开某个技术模块吗？比如：
  - 🔧 STM32CubeIDE的详细配置
  - 📱 Flutter基础BLE代码
  - 🧠 Edge Impulse训练教程
  - 📊 PCB设计规范

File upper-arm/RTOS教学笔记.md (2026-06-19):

# RTOS 教学笔记

这份文档用于记录 U575 工程里的 FreeRTOS 学习笔记、调试方法和后续说明。以后如果说“保存到文案里”，就继续追加到这里。

## 1. 从裸机思维切换到 RTOS 思维

裸机程序通常把主要业务写在 `main.c` 的 `while (1)` 里：

```c
while (1)
{
  read_sensor();
  printf("data\r\n");
  HAL_Delay(100);
}
```

当前 U575 工程启用了 FreeRTOS。`main.c` 执行到：

```c
osKernelStart();
```

之后，CPU 由 RTOS 调度器接管，正常不会再回到 `main.c` 后面的主循环。因此业务代码应该写到任务函数里，而不是写在 `main.c` 的 `while (1)` 中。

## 2. 任务是什么

任务可以理解成“同时运行的多个小主循环”。每个任务都有自己的 `for (;;)`：

```c
void StartSensorTask(void *argument)
{
  for (;;)
  {
    read_sensor();
    osDelay(5);
  }
}
```

`osDelay(5)` 表示当前任务休息 5ms，把 CPU 让给其他任务。RTOS 任务里一般用 `osDelay()`，不要用 `HAL_Delay()`。

## 3. 当前工程的任务分工

当前工程里比较重要的任务：

- `SensorTask`：负责采集传感器，比如 LSM6DSR 陀螺仪/加速度计。
- `DebugTask`：适合放串口打印调试代码。
- `DisplayTask`：负责屏幕和触摸测试。
- `AlgoTask`：后续适合放康复动作识别、滤波、算法逻辑。
- `WirelessTask`：后续适合放无线通信逻辑。

原则：采样任务尽量短、快、稳定；打印、显示、无线发送这些慢操作放到单独任务中。

## 4. 队列是什么

队列可以理解成任务之间传数据的“邮箱”。

`SensorTask` 采集 IMU 后，把数据放进队列：

```c
osMessageQueuePut(imuFrameQueueHandle, &imu_data, 0U, 0U);
```

`DebugTask` 从队列取出数据再打印：

```c
osMessageQueueGet(imuFrameQueueHandle, &imu_data, NULL, 1000);
```

这样 `SensorTask` 不需要直接负责打印，采样不会被串口输出拖慢。

## 5. IMU 原始数据打印方法

工程里已经添加了 `printf` 重定向，输出到 `USART2`：

- PA2：USART2_TX，接 USB-TTL 的 RX。
- PA3：USART2_RX，接 USB-TTL 的 TX。
- 波特率：115200。
- 串口格式：8N1。

工程里也封装了 IMU 原始数据打印接口：

```c
void LSM6DSR_PrintRaw(const LSM6DSR_Data_t *data);
```

推荐在 `DebugTask` 中这样使用：

```c
void StartDebugTask(void *argument)
{
  /* USER CODE BEGIN DebugTask */
  LSM6DSR_Data_t imu_data;

  for (;;)
  {
    if (osMessageQueueGet(imuFrameQueueHandle, &imu_data, NULL, 1000) == osOK)
    {
      osMutexAcquire(uart2MutexHandle, osWaitForever);
      LSM6DSR_PrintRaw(&imu_data);
      osMutexRelease(uart2MutexHandle);
    }

    osDelay(100);
  }
  /* USER CODE END DebugTask */
}
```

不要在 DMA 回调、中断回调里 `printf`，否则容易阻塞或影响实时性。

## 6. 三条基本规则

1. 不要把业务代码写到 `main.c` 的 `while (1)` 里。
2. 不要在中断回调或 DMA 回调里 `printf`。
3. RTOS 任务里延时优先用 `osDelay()`，不要用 `HAL_Delay()`。

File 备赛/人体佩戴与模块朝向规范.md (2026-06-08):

# 人体佩戴与模块朝向规范

## 一、目的

本规范用于统一 MVP 版本中各传感器、主控盒、肌电电极和连接线在人体上的安装位置、固定方式和坐标方向定义，避免因为佩戴位置不一致导致采集数据漂移、动作识别不稳定或角度计算误差过大。

本规范适用于当前版本的以下模块：

- 上臂 IMU（逐飞 IMU660RB，核心芯片 LSM6DSRTR）
- 前臂/手腕 IMU（逐飞 IMU660RB，核心芯片 LSM6DSRTR）
- 肌电电极与肌电模块
- 主控盒
- OLED 显示模块
- 蓝牙模块
- 电池与走线结构

## 二、整体佩戴结构

MVP 版本建议采用“两点传感 + 一体主控盒 + 单路肌电”的结构。

```text
患侧上臂外侧：主控盒 + 上臂 IMU + 肌电模块
患侧前臂远端背侧：前臂/手腕 IMU
患侧肱二头肌：肌电电极
```

推荐结构说明：

1. 上臂位置集中布置主控、显示、蓝牙、电池和上臂 IMU。
2. 前臂位置只保留一个轻量 IMU 节点，减小运动负担。
3. 肌电电极靠近目标肌肉放置，肌电模块尽量靠近主控盒，减少线长和噪声干扰。

当前版本中，两个姿态节点均优先采用逐飞 `IMU660RB` 模块，以统一安装方式、通信方式和驱动接口。

## 三、上臂 IMU 安装规范

### 1. 安装位置

上臂 IMU 固定在患侧上臂外侧中段。

推荐位置：

- 位于肩峰与肘关节连线的中点附近。
- 或肘关节上方约 8 cm 至 12 cm 的位置。
- 贴近肱骨外侧，不放置在上臂正前方或正后方。

不推荐位置：

- 肘关节附近，容易受到屈肘动作挤压。
- 肱二头肌最鼓起的正前侧，容易因肌肉形变导致模块晃动。
- 上臂后侧，佩戴舒适性和重复定位性较差。

### 2. 固定方式

- 使用弹性臂带或魔术贴绑带固定。
- IMU 模块建议装入轻质小壳体。
- 壳体与皮肤接触侧建议增加薄海绵、防滑硅胶或软垫。
- 固定后要求模块在做屈肘和外展动作时不明显旋转。

### 3. 模块朝向

建议将模块长边沿上臂纵向排布，传感器板正面朝身体外侧。

推荐本地坐标定义：

- `X 轴`：沿上臂长轴向下，指向肘部。
- `Y 轴`：由手臂指向身体外侧。
- `Z 轴`：垂直皮肤表面向外。

如果实际 PCB 坐标与上述定义不完全一致，应在软件中建立安装方向映射，不允许凭经验混用多个坐标定义。

## 四、前臂/手腕 IMU 安装规范

### 1. 安装位置

推荐安装在患侧前臂远端背侧，优先于普通手表佩戴位。

推荐位置：

- 距离腕关节上方约 4 cm 至 6 cm。
- 位于前臂背侧，略偏桡侧。
- 保持与前臂长轴大致平行。

这样布置的原因：

- 比纯手腕表位更稳定。
- 更利于观察前臂旋前旋后和腕部姿态变化。
- 受手掌抓握动作直接干扰较小。

不推荐位置：

- 手掌背面，动作干扰过大。
- 手腕掌侧，舒适性差，且容易影响日常动作。
- 正好位于尺骨茎突等突出骨点正上方，容易松动或硌手。

### 2. 固定方式

- 使用宽表带、魔术贴绑带或织物绑带固定。
- 固定力度应高于普通手表，但不能影响血液循环。
- 要求旋前旋后和腕部动作时模块不明显滑移。

### 3. 模块朝向

建议与上臂 IMU 采用尽可能一致的朝向定义。

推荐本地坐标定义：

- `X 轴`：沿前臂长轴向下，指向手部。
- `Y 轴`：由前臂指向身体外侧。
- `Z 轴`：垂直皮肤表面向外。

统一坐标方向的好处是便于计算上臂与前臂的相对姿态，减少后续变换复杂度。

## 五、肌电电极安装规范

### 1. 当前推荐采集肌肉

MVP 阶段优先使用单路肌电，并建议优先检测患侧肱二头肌。

原因：

- 与屈肘训练直接相关。
- 电极位置相对容易确定。
- 更容易体现主动参与而非被动摆动。

### 2. 电极位置

采集电极建议贴附于肱二头肌肌腹位置。

定位方法：

1. 让受试者尝试轻微屈肘。
2. 找到上臂前侧最明显鼓起的位置。
3. 沿肌纤维方向放置两个采集电极。

推荐布置：

- 两个采集电极间距约 20 mm。
- 沿上臂纵向排列。
- 电极尽量保持与肌纤维方向一致。

参考电极建议放置位置：

- 肘部鹰嘴附近。
- 或前臂较明显的骨性区域。

不推荐把参考电极贴在同一块主要收缩肌肉上。

### 3. 皮肤处理要求

- 佩戴前擦净皮肤汗液和油脂。
- 必要时可用酒精棉片简单清洁。
- 如毛发较多，应适度清理，以提高接触质量。

### 4. 肌电模块位置

- 肌电模块本体建议固定在上臂主控盒附近。
- 不建议直接悬空挂在线缆中间。
- 肌电导线应尽量短，并沿手臂方向贴附固定。

## 六、主控盒安装规范

### 1. 推荐位置

主控盒建议固定在患侧上臂外侧偏后位置。

推荐原因：

- 靠近上臂 IMU 和肌电模块，布线方便。
- 不易在屈肘时与胸前或桌面发生碰撞。
- OLED 朝外，便于演示和观察。

### 2. 盒内模块建议

主控盒建议集成以下内容：

- STM32 主控板
- OLED 屏
- 蓝牙模块
- 电池
- 充电模块
- 上臂 IMU 或其连接接口
- 肌电模块或其接口

### 3. 外壳设计要求

- 轻量化，避免对上臂造成明显下坠。
- 边角圆滑，避免刮擦皮肤。
- OLED 开窗朝外。
- 预留充电口和开关位置。
- 预留绑带穿孔或固定槽。

## 七、OLED 与蓝牙模块朝向建议

### OLED

- 建议朝身体外侧。
- 字体方向与佩戴者自然站立时的观察方向一致。
- 尽量避免横向倒置，否则演示时不直观。

### 蓝牙模块

- 天线区域尽量远离大面积金属和电池。
- 天线方向优先朝外侧或上方。
- 尽量不要把天线完全贴在人体一侧。

## 八、电池与走线规范

### 1. 电池位置

- 优先放置在上臂主控盒内部。
- 电池应贴合壳体内壁固定，避免晃动。

### 2. 走线原则

- 线缆尽量贴附手臂走向布置。
- 可使用医用胶带、织物贴或小型束线结构固定。
- 避免导线跨越肘窝或手腕高频弯折区。

### 3. 肌电线特殊要求

- 肌电导线尽量短。
- 尽量远离蓝牙天线和高频数字线。
- 尽量与电源线分开走线，减少干扰。

## 九、人体坐标与传感器坐标统一规范

为保证算法和标定一致，建议统一定义人体局部坐标系。

### 1. 上臂局部坐标系

- 纵向正方向：从肩部指向肘部。
- 外侧正方向：从身体指向手臂外侧。
- 离体表正方向：垂直皮肤向外。

### 2. 前臂局部坐标系

- 纵向正方向：从肘部指向手部。
- 外侧正方向：从身体指向前臂外侧。
- 离体表正方向：垂直皮肤向外。

### 3. 软件要求

- 所有姿态解算和角度计算都必须基于统一坐标定义。
- 如果硬件安装方向不同，必须通过旋转矩阵或轴变换在软件层统一。

## 十、佩戴校准流程

建议每次开机训练前执行一次简短校准。

### 标准校准姿势

- 取坐位或站位自然姿势。
- 上臂自然下垂。
- 前臂自然放松。
- 保持静止 3 秒。

### 校准目的

- 记录重力方向基准。
- 建立初始零位姿态。
- 减少不同佩戴角度带来的系统误差。

## 十一、演示前检查清单

每次演示前建议按以下项目快速检查：

1. 上臂 IMU 是否固定牢靠。
2. 前臂 IMU 是否发生旋转偏移。
3. 肌电电极是否贴紧、是否松动。
4. 肌电信号静息与发力是否有明显差异。
5. OLED 显示方向是否正确。
6. 蓝牙是否已连接。
7. 导线是否影响屈肘和抬臂动作。

## 十二、当前 MVP 推荐定版结构

当前版本建议固定为以下结构，不再继续发散：

- 患侧上臂外侧主控盒，集成主控、OLED、蓝牙、电池、上臂 IMU、肌电模块。
- 患侧前臂远端背侧单独固定一个 IMU 模块。
- 患侧肱二头肌布置单路肌电电极。

这套结构兼顾了可实现性、佩戴稳定性、展示效果和算法一致性，适合作为当前 MVP 的定版方案。

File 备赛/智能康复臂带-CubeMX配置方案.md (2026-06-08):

# AI-RehabBand 智能康复臂带 CubeMX 配置方案

本文档基于 `智能康复臂带-MVP方案.md`，面向 STM32U575RIT6 单节点版本，用于在 STM32CubeMX 中完成工程初始化、外设分配、中断/DMA、时钟和基础工程选项配置。

## 1. 配置目标

MVP 阶段需要在 STM32U575RIT6 上同时完成：

- 单个 IMU660RB 采集：每块 STM32U575RIT6 只连接 1 个陀螺仪/IMU
- 1 路简化肌电 ADC 采集
- P169H002 LCD 触摸显示屏显示刷新（LCD 驱动：ST7789T3，触摸：CST816D）
- 无线数据串口模块接口（USART1，HM-10 / ESP32-C3 / 其他 3.3V TTL 串口透传模块）
- 无线调试串口接口（USART2，独立打印日志和调试命令）
- PA12 单按键预留，当前不参与业务逻辑
- 蜂鸣器或 LED 异常提醒
- 50Hz-100Hz 运动处理主循环
- 200Hz-500Hz 肌电采样

推荐 CubeMX 配置策略：

- 单个 IMU 使用 SPI1，CS 采用 GPIO 软件片选，IMU 数据读取使用 SPI1 RX/TX DMA；第二块单片机连接另一颗 IMU 时复用同一套 SPI1 配置。
- P169H002 的 LCD 显示单独使用一路 SPI，触摸 CST816D 使用 I2C，避免显示刷新影响 IMU 采样。
- 肌电使用 ADC + DMA 循环采样。
- 无线数据串口使用 USART1，调试无线串口使用 USART2，接收建议中断或 DMA。
- 使用 TIM 定时触发采样节拍，保证算法周期稳定。

## 2. MCU 与工程基础设置

### 2.1 MCU 选择

在 CubeMX 中从 MCU Selector 选择具体芯片型号：

```text
STM32U575RIT6
```

不要按 NUCLEO-U575ZI-Q 或 STM32U575ZITx 建工程。`RIT6` 是 LQFP64 封装，引脚数量少于 ZI 系列，SPI、USART、ADC 和调试口的引脚复用需要按 LQFP64 实际可用引脚重新分配。

### 2.2 Project Manager

推荐配置：

```text
Project Name: AI_RehabBand_MVP
Toolchain / IDE: MDK-ARM 或 STM32CubeIDE
Firmware Package: STM32Cube FW_U5 最新稳定版本
Application Structure: Basic
```

Code Generator 建议：

```text
Generate peripheral initialization as a pair of '.c/.h' files per peripheral: Enable
Keep User Code when re-generating: Enable
Delete previously generated files when not re-generated: Disable
Set all free pins as analog: Enable
```

## 3. 系统时钟配置

### 3.1 RCC

若开发板带外部高速晶振：

```text
HSE: Crystal/Ceramic Resonator
LSE: Crystal/Ceramic Resonator
```

若不需要 RTC，LSE 可不启用。

若不确定板载晶振情况，先使用内部时钟：

```text
HSE: Disable
SYSCLK Source: MSI 或 HSI16
```

### 3.2 Clock Configuration

推荐主频：

```text
SYSCLK: 160 MHz
HCLK: 160 MHz
APB1: 160 MHz
APB2: 160 MHz
APB3: 160 MHz
```

理由：

- 160MHz 对姿态解算、显示刷新和串口通信足够。
- STM32U575RIT6 性能余量较大，后续可加入轻量模型。
- 若使用电池供电并追求续航，调试稳定后可降到 80MHz。

电源配置：

```text
Power Regulator Voltage Scale: Scale 1
```

## 4. 引脚与外设总览

以下为推荐分配，实际引脚需根据开发板排针和原理图调整。

| 功能 | CubeMX 外设 | 推荐用途 |
|---|---|---|
| 本节点 IMU660RB | SPI1：PA5/PA6/PA7 + PA4 CS | 本节点 IMU 数据读取 |
| P169H002 LCD 显示 ST7789T3 | SPI3：PC10/PC12 + PA15/PB8/PB9/PA8 | LCD 显示刷新 |
| P169H002 触摸 CST816D | I2C1：PB6/PB7 + PC4/PC5 | 触摸 I2C、复位、中断 |
| 肌电模拟输入 | ADC1_IN1：PC0 | EMG 原始信号采样 |
| 无线数据串口接口 | USART1：PA9/PA10 | 数据上传、板间同步或手机透传 |
| 无线调试串口接口 | USART2：PA2/PA3 | 调试日志、参数下发、printf |
| RTOS 节拍 | FreeRTOS SysTick | 任务调度，SensorTask 10ms 周期 |
| 肌电节拍 | TIM3 TRGO | 500Hz EMG ADC 触发 |
| 按键预留 | GPIO_Input：PA12 | 单按键预留，当前不起作用 |
| LED/蜂鸣器 | GPIO_Output / PWM | 状态和异常提醒 |
| 调试下载 | SYS | SWD |
| 调试日志 | USART2：PA2/PA3 | 独立无线调试串口 |

### 4.1 STM32U575RIT6 推荐具体引脚分配

以下分配按 STM32U575RIT6 LQFP64 封装整理，当前只配置一个 IMU 节点，优先保证本节点 IMU、P169H002 LCD 触摸显示屏、无线串口和肌电采样互不冲突。CubeMX 中按 `Pin Name` 选择即可，硬件原理图上也按这些网络名标注。

| 模块 | 信号 | STM32U575RIT6 引脚 | CubeMX 配置 | 说明 |
|---|---|---|---|---|
| 本节点 IMU660RB | IMU_SCK | PA5 | SPI1_SCK | SPI1，Mode 3 |
| 本节点 IMU660RB | IMU_MISO | PA6 | SPI1_MISO | IMU -> STM32 |
| 本节点 IMU660RB | IMU_MOSI | PA7 | SPI1_MOSI | STM32 -> IMU |
| 本节点 IMU660RB | IMU_CS | PA4 | GPIO_Output | 软件片选，默认高电平，读写时拉低 |
| 本节点 IMU660RB | IMU_INT | PC8 | GPIO_EXTI，可选 | 数据就绪中断，MVP 可不接 |
| P169H002 LCD 显示 | LCD_SCL | PC10 | SPI3_SCK | ST7789T3 SCL |
| P169H002 LCD 显示 | LCD_SDA | PC12 | SPI3_MOSI | ST7789T3 SDA，显示写入 |
| P169H002 LCD 显示 | LCD_SDO | PC11 | SPI3_MISO，可选 | 显示只写时可不接 |
| P169H002 LCD 显示 | LCD_CS | PA15 | GPIO_Output | ST7789T3 CS，低电平选中 |
| P169H002 LCD 显示 | LCD_DC | PB8 | GPIO_Output | ST7789T3 RS/DC，数据/命令选择 |
| P169H002 LCD 显示 | LCD_RST | PB9 | GPIO_Output | ST7789T3 RESET，低电平复位 |
| P169H002 LCD 显示 | LCD_BL | PA8 | GPIO_Output 或 TIM PWM | 背光控制，按驱动板电路决定有效电平 |
| P169H002 触摸 | TP_SCL | PB6 | I2C1_SCL | CST816D CTP_SCL |
| P169H002 触摸 | TP_SDA | PB7 | I2C1_SDA | CST816D CTP_SDA |
| P169H002 触摸 | TP_RST | PC5 | GPIO_Output | CST816D CTP_TRST，低电平复位 |
| P169H002 触摸 | TP_INT | PC4 | GPIO_Input 或 GPIO_EXTI | CST816D CTP_TINT，触摸中断 |
| 肌电模块 | EMG_ADC | PC0 | ADC1_IN1 | 模拟输入，0-3.3V |
| 无线数据串口模块 | WIRELESS_RXD | PA9 | USART1_TX | STM32 发，模块收 |
| 无线数据串口模块 | WIRELESS_TXD | PA10 | USART1_RX | 模块发，STM32 收 |
| 无线数据串口模块 | WIRELESS_EN | PB0 | GPIO_Output，可选 | 模块使能，不需要可不接 |
| 无线数据串口模块 | WIRELESS_STATE | PB1 | GPIO_Input，可选 | 连接状态，不需要可不接 |
| 无线调试串口模块 | DBG_RXD | PA2 | USART2_TX | STM32 调试输出，接模块 RXD |
| 无线调试串口模块 | DBG_TXD | PA3 | USART2_RX | 模块 TXD，STM32 接收调试命令 |
| 按键预留 | KEY_RESERVED | PA12 | GPIO_Input | 上拉输入，仅预留，当前不起作用 |
| 提示输出 | LED_STATUS | PC6 | GPIO_Output | 运行状态指示 |
| 提示输出 | BUZZER | PB2 | GPIO_Output 或 TIM PWM | 异常提醒 |
| 调试下载 | SWDIO | PA13 | SYS_JTMS-SWDIO | 保留 SWD |
| 调试下载 | SWCLK | PA14 | SYS_JTCK-SWCLK | 保留 SWD |
| 复位 | NRST | NRST | Reset | 建议引出到下载口 |

注意事项：

- `PA13`、`PA14` 必须保留给 SWD 下载调试。
- `PA15`、`PB3`、`PB4` 属于 JTAG 相关脚，使用 SWD 调试时可以作为普通 GPIO/外设使用；本方案只占用 `PA15` 做 LCD_CS，不影响 SWD 下载。
- P169H002 LCD只写数据时可以不接 `PC11/SPI3_MISO`，这样 LCD 排针可以做 7 线：`3V3/GND/SCL/SDA/CS/DC/RST/BL`，其中 BL 可直接上拉常亮或接 `PA8` 控制。
- 如果你的 LCD 模块排针标的是 `SCK/SDA/A0/RES/CS/BLK`，对应关系是：`SCK->PC10`，`SDA->PC12`，`A0/DC->PB8`，`RES/RST->PB9`，`CS->PA15`，`BLK->PA8`。
- 无线数据串口最小接口是 `3V3`、`GND`、`PA9 USART1_TX`、`PA10 USART1_RX`；`PB0 EN` 和 `PB1 STATE` 只是预留。
- 无线调试串口最小接口是 `3V3`、`GND`、`PA2 USART2_TX`、`PA3 USART2_RX`，用于 printf 日志和现场调参。
- 肌电 `PC0/ADC1_IN1` 前端必须限幅到 0-3.3V，不能输入负压或超过 VDDA 的电压。

## 5. SYS 与调试接口

在 `System Core > SYS` 中配置：

```text
Debug: Serial Wire
```

不要关闭 SWDIO/SWCLK 对应引脚，否则后续可能无法下载调试。

## 6. GPIO 配置

### 6.1 IMU 软件片选和中断引脚

本节点只配置 1 个 IMU，使用 SPI1。SPI1 使用软件片选，CubeMX 中 `Hardware NSS Signal` 设为 `Disable`，`NSS Signal Type` 设为 `Software`。IMU 至少需要一个 GPIO 作为 CS 引脚：

```text
IMU_CS: GPIO_Output, default High
```

若使用 IMU 的数据就绪中断，可增加：

```text
IMU_INT: GPIO_EXTI
```

MVP 推荐先不用 IMU INT，使用定时器 100Hz 轮询读取，开发更稳。
软件片选控制原则：

```text
空闲状态: CS = High
开始通信: CS = Low
通信完成: CS = High
```

CS 拉低和拉高建议封装成宏或函数，避免不同驱动里重复写错。

### 6.2 显示屏控制引脚

P169H002 / ST7789T3 常用 LCD 控制引脚：

```text
LCD_CS:  GPIO_Output, default High  // 软件片选
LCD_DC:  GPIO_Output, default Low
LCD_RST: GPIO_Output, default High
LCD_BL:  GPIO_Output 或 TIM PWM
```

若背光只需要常亮，`LCD_BL` 配为 GPIO_Output 即可。

### 6.3 按键预留

当前只保留 1 个按键引脚，先不参与模式切换、开始停止或中断逻辑。

```text
KEY_RESERVED: PA12, GPIO_Input, Pull-Up, No EXTI
```

后续如果需要启用按键，再把 PA12 改为 GPIO_EXTI 或在 UiTask 中轮询消抖。

### 6.4 状态 LED / 蜂鸣器

```text
LED_STATUS: GPIO_Output
BUZZER: PB2, GPIO_Output, default High
```

当前 `.ioc` 使用 `PB2` 作为 BUZZER，默认输出高电平。若后续蜂鸣器需要不同提示音，再把 BUZZER 改为合适的 TIM PWM 输出。

## 7. 单 IMU660RB 配置

IMU660RB 核心芯片为 LSM6DSRTR，常见接口为 SPI。当前每块 STM32U575RIT6 只连接 1 颗 IMU，使用 SPI1。另一块单片机连接远端 IMU 时，也按本节复用同样配置。

### 7.1 SPI1 - 本节点 IMU

在 `Connectivity > SPI1` 中配置：

```text
Mode: Full-Duplex Master
Hardware NSS Signal: Disable
NSS Signal Type: Software
Data Size: 8 Bits
First Bit: MSB First
Clock Polarity: High
Clock Phase: 2 Edge
Baud Rate Prescaler: 32 或 64
```

初始 SPI 频率建议控制在 1MHz-5MHz，传感器初始化稳定后可提高。

LSM6DS 系列常用 SPI Mode 3：

```text
CPOL = 1
CPHA = 1
```

即 CubeMX 中 `Clock Polarity: High`，`Clock Phase: 2 Edge`。

### 7.2 SPI1 DMA - IMU 数据读取

IMU 需要 100Hz 稳定读取，建议 SPI1 同时启用 RX DMA 和 TX DMA。读取寄存器时，TX DMA 发送寄存器地址和 dummy 字节，RX DMA 接收返回数据。

在 `Connectivity > SPI1 > DMA Settings` 中添加：

```text
DMA Channel: GPDMA1 Channel 0
DMA Request: SPI1_RX
Mode: Normal
Data Width Peripheral: Byte
Data Width Memory: Byte
Increment Address Peripheral: Disable
Increment Address Memory: Enable
Priority: High
```

再添加：

```text
DMA Channel: GPDMA1 Channel 1
DMA Request: SPI1_TX
Mode: Normal
Data Width Peripheral: Byte
Data Width Memory: Byte
Increment Address Peripheral: Disable
Increment Address Memory: Enable
Priority: High
```

U5 系列的 GPDMA 通道不是固定绑定外设，关键是同一个 DMA 通道里选择正确的 `DMA Request`。本方案固定写法是：`GPDMA1 Channel 0 + SPI1_RX`，`GPDMA1 Channel 1 + SPI1_TX`。

SPI1 DMA 使用原则：

```text
1. IMU_CS 拉低
2. 调用 HAL_SPI_TransmitReceive_DMA()
3. 在 HAL_SPI_TxRxCpltCallback() 中拉高 IMU_CS
4. 置位 imu_dma_done 标志或释放 RTOS 信号量
```

不要在 DMA 传输未完成时拉高 CS，否则 IMU 本次读数可能不完整。
### 7.3 SPI2 说明

当前节点不配置第二颗 IMU，因此 `SPI2` 不作为必配外设。`PB12/PB13/PB14/PB15` 可保留为空闲 GPIO，后续需要扩展传感器时再启用。

### 7.4 IMU 采样参数

这部分不是 CubeMX 配置，而是在驱动初始化中写寄存器：

```text
加速度计量程: +-4g 或 +-8g
陀螺仪量程: +-500 dps 或 +-1000 dps
ODR: 104Hz
采样读取频率: 100Hz
```

MVP 推荐：

```text
IMU ODR: 104Hz
算法周期: 100Hz
```

这样能满足动作识别和角度计算需求。

## 8. 肌电 ADC 配置

肌电模块若输出模拟包络或模拟原始电压，接入 ADC。

### 8.1 ADC1

在 `Analog > ADC1` 中配置：

```text
Mode: Independent mode
Resolution: 12-bit
Data Alignment: Right alignment
Scan Conversion Mode: Disabled
Continuous Conversion Mode: Disabled
External Trigger Conversion Source: TIM3 TRGO / TIM3 TRGO Event / TIM3 Update Event
External Trigger Conversion Edge: Rising Edge
DMA Continuous Requests: Enable
Overrun: Overrun data overwritten
Sampling Time: 47.5 cycles 或更高
```

通道示例：

```text
ADC1_IN1: EMG_ADC
```

具体 INx 根据开发板可用 ADC 引脚调整。

### 8.2 ADC DMA

在 ADC1 的 DMA Settings 中添加：

```text
DMA Request: ADC1
Mode: Circular
Data Width Peripheral: Half Word
Data Width Memory: Half Word
Increment Address Peripheral: Disable
Increment Address Memory: Enable
Priority: High
```

建议 DMA 缓冲区：

```text
emg_adc_buf[64] 或 emg_adc_buf[128]
```

500Hz 采样下，64 点约 128ms 窗口，适合做整流、平均值、RMS 或包络阈值判断。

## 9. 定时器配置

### 9.1 TIM6 - 100Hz 系统算法节拍

用途：

- 触发主循环读取本节点 IMU
- 更新姿态解算
- 更新动作识别
- 更新评分状态

在 `Timers > TIM6` 中配置：

```text
Mode: Activated
Prescaler: 16000 - 1
Counter Period: 100 - 1
Trigger Event Selection: Update Event
```

当 TIM6 时钟为 160MHz 时：

```text
160MHz / 16000 / 100 = 100Hz
```

FreeRTOS 启用后，TIM6 不再作为算法中断节拍使用，可不启用 TIM6 global interrupt。

### 9.2 TIM3 - 500Hz 肌电 ADC 触发

用途：

- 稳定触发 ADC 采样

在 `Timers > TIM3` 中配置：

```text
Mode: Activated
Prescaler: 16000 - 1
Counter Period: 20 - 1
Trigger Event Selection: Update Event
```

当 TIM3 时钟为 160MHz 时：

```text
160MHz / 16000 / 20 = 500Hz
```

TIM3 不需要开中断，主要用于 TRGO / Update Event 触发 ADC。若 ADC 触发源列表里没有精确的 `TIM3 TRGO`，优先找 `TIM3_TRGO`、`TIM3 TRGO Event`、`TIM3 Update Event` 这类名称。

## 10. 显示屏配置

P169H002 的 LCD 显示驱动为 ST7789T3，触摸芯片为 CST816D。LCD 使用 4 线串行 SPI，触摸使用 I2C。

### 10.1 SPI3 - P169H002 LCD 显示 ST7789T3

在 `Connectivity > SPI3` 中配置：

```text
Mode: Full-Duplex Master 或 Transmit Only Master
Hardware NSS Signal: Disable
NSS Signal Type: Software
Data Size: 8 Bits
First Bit: MSB First
Clock Polarity: Low
Clock Phase: 1 Edge
Baud Rate Prescaler: 4 或 8
```

ST7789 常用 SPI Mode 0：

```text
CPOL = 0
CPHA = 0
```

P169H002 LCD 显示刷新推荐使用阻塞 SPI 先打通，后续再改 DMA。

### 10.2 SPI3 DMA 可选

若需要更流畅刷新，在 SPI3 中添加 TX DMA：

```text
DMA Request: SPI3_TX
Mode: Normal
Data Width Peripheral: Byte
Data Width Memory: Byte
Priority: Medium
```

MVP 的 LCD 显示内容以文字、角度、次数和状态为主，不强制使用 DMA。ST7789T3 与 ST7789 系列驱动相近，但 P169H002 的分辨率、偏移量和初始化命令需要按实物资料校准。

### 10.3 P169H002 LCD 接口排针建议

建议在硬件上给 P169H002 预留接口：

```text
LCD_VCC  -> 3V3
LCD_GND  -> GND
LCD_SCL  -> SPI3_SCK
LCD_SDA  -> SPI3_MOSI
LCD_CS   -> GPIO_Output
LCD_DC   -> GPIO_Output
LCD_RST  -> GPIO_Output
LCD_BL   -> GPIO_Output 或 PWM
TP_SCL   -> I2C1_SCL / PB6
TP_SDA   -> I2C1_SDA / PB7
TP_RST   -> GPIO_Output / PC5
TP_INT   -> GPIO_Input 或 GPIO_EXTI / PC4
```

若屏幕模块带 MISO/SDO 引脚，MVP 阶段可以不接；ST7789T3 显示通常只需要写入数据。
### 10.4 CST816D 触摸 I2C 配置

在 `Connectivity > I2C1` 中配置：

```text
I2C Speed Mode: Fast Mode
I2C Speed Frequency: 400kHz
Addressing Mode: 7-bit
```

触摸引脚：

```text
TP_SCL -> PB6 / I2C1_SCL
TP_SDA -> PB7 / I2C1_SDA
TP_RST -> PC5 / GPIO_Output
TP_INT -> PC4 / GPIO_Input，后续需要中断时改 GPIO_EXTI
```

当前阶段如果只想先点亮屏幕，可以先配置 PB6/PB7/PC4/PC5 为预留，不写触摸驱动；但原理图建议把这 4 根线引出。

## 11. 无线串口接口配置

本节点配置两路串口：`USART1` 作为无线数据串口，`USART2` 作为无线调试串口。两路都可以接 HM-10、ESP32-C3 串口透传模块或其他 3.3V TTL 串口模块，CubeMX 中按普通 UART 处理。

### 11.1 USART1 - 无线数据串口

在 `Connectivity > USART1` 中配置：

```text
Mode: Asynchronous
Baud Rate: 115200
Word Length: 8 Bits
Parity: None
Stop Bits: 1
Hardware Flow Control: None
Oversampling: 16 Samples
```

无线数据串口接口排针建议：

```text
WIRELESS_VCC   -> 3V3
WIRELESS_GND   -> GND
WIRELESS_TXD   -> USART_RX   // 模块发，STM32 收
WIRELESS_RXD   -> USART_TX   // 模块收，STM32 发
WIRELESS_EN    -> GPIO_Output，可选
WIRELESS_STATE -> GPIO_Input，可选
```

最小可用接口只需要 4 根线：`3V3`、`GND`、`USART_TX`、`USART_RX`。如果模块没有 EN/STATE 引脚，可以不配置。

注意无线串口模块电平：

- HM-10 多数为 3.3V TTL，可直连 STM32。
- ESP32-C3 也是 3.3V TTL。
- 不要接 5V 串口电平。

### 11.2 USART2 - 无线调试串口

在 `Connectivity > USART2` 中配置：

```text
Mode: Asynchronous
Baud Rate: 115200
Word Length: 8 Bits
Parity: None
Stop Bits: 1
Hardware Flow Control: None
Oversampling: 16 Samples
```

无线调试串口接口排针建议：

```text
DBG_VCC -> 3V3
DBG_GND -> GND
DBG_RXD -> PA2 / USART2_TX   // STM32 发，调试模块收
DBG_TXD -> PA3 / USART2_RX   // 调试模块发，STM32 收
```

用途建议：

```text
USART1: 训练数据、板间数据、手机端通信
USART2: printf 日志、调试命令、阈值参数临时修改
```

调试串口不要发送高频完整 IMU 原始数据，建议只发降频后的摘要，例如 10Hz 的角度、状态和错误码，避免阻塞系统。
### 11.3 UART 接收方式

MVP 推荐：

```text
USART1 global interrupt: Enable
USART2 global interrupt: Enable
```

使用中断接收无线数据串口和调试串口命令，例如：

```text
START
STOP
MODE,0
MODE,1
MODE,2
```

训练结果发送格式建议：

```text
RESULT,mode,action,count,angle_max,score,emg_rate,abnormal_count
```

示例：

```text
RESULT,1,0,12,96,88,74,1
```

## 12. NVIC 中断优先级建议

在 `System Core > NVIC` 中配置。因为本工程启用 FreeRTOS，凡是在中断回调里调用 `osSemaphoreRelease`、`osMessageQueuePut`、`xSemaphoreGiveFromISR`、`xQueueSendFromISR` 等 RTOS API 的中断，抢占优先级数值必须 `>= configLIBRARY_MAX_SYSCALL_INTERRUPT_PRIORITY`。

CubeMX 默认常见配置：

```text
configLIBRARY_MAX_SYSCALL_INTERRUPT_PRIORITY = 5
```

STM32 中断优先级数字越小，优先级越高。因此能调用 RTOS FromISR API 的中断不要设成 0-4，建议如下：

| 中断 | 抢占优先级 | 用途 | 是否允许调用 RTOS FromISR API |
|---|---:|---|---|
| SPI1 RX DMA | 5 | IMU 数据接收完成 | 是，释放 `imuDmaDoneSem` |
| SPI1 TX DMA | 5 | IMU 发送完成 | 通常不需要，保持同级 |
| ADC1 DMA | 6 | 肌电采样半满/满缓冲 | 是，可释放 `adcHalfCpltSem/adcCpltSem` |
| USART1 Global | 7 | 无线数据串口接收 | 是，可投递命令队列 |
| USART2 Global | 8 | 无线调试串口接收 | 是，可投递调试命令队列 |
| TP_INT / EXTI4 | 9 | CST816D 触摸中断，可选 | 是，可通知触摸任务 |
| IMU_INT / EXTI8 | 9 | IMU 数据就绪中断，可选 | 是，可通知 SensorTask |
| SPI3 DMA TX | 10 | LCD 刷新完成，可选 | 是，但建议只释放显示信号量 |
| TIM17 Global | 15 | HAL timebase | 否，只给 HAL tick 使用 |
| PA12 Key | - | GPIO_Input 预留，不启用 EXTI | 否 |

原则：

- `TIM17 global interrupt` 必须开启，因为 SYS timebase 改为 TIM17 后，HAL tick 依赖它。
- TIM17 优先级设最低，例如抢占优先级 15，避免影响 SPI/ADC/UART。
- SPI1 DMA、ADC DMA、USART1、USART2 后续大概率会在中断里释放信号量或投递队列，所以统一设为 5 或更大的数字。
- 如果某个中断绝对不调用 RTOS API，只置 `volatile` 标志，理论上可以设为 0-4；本项目为了避免后期维护踩坑，不建议这样做。
- 不要在任何中断里做姿态解算、RMS 计算、LCD 刷新或 printf。
## 13. DMA 汇总

建议强制启用：

```text
SPI1_RX -> GPDMA1 Channel 0, DMA Request SPI1_RX, Normal, High Priority
SPI1_TX -> GPDMA1 Channel 1, DMA Request SPI1_TX, Normal, High Priority
ADC1    -> DMA Circular, High Priority
```

可选启用：

```text
SPI3_TX  -> DMA Normal, Medium Priority
USART1_RX -> DMA Circular 或中断接收
USART1_TX -> DMA Normal
USART2_RX -> DMA Circular 或中断接收
USART2_TX -> DMA Normal
```

当前版本建议强制启用 `SPI1_RX`、`SPI1_TX` 和 `ADC1` DMA。USART1/USART2 可以先用中断接收，稳定后再改 DMA。LCD 的 SPI3_TX DMA 可后续优化显示刷新时再启用。
## 14. FreeRTOS 配置建议

当前版本建议启用 FreeRTOS，使用 CMSIS-RTOS v2。可以把 FreeRTOS 理解成：以前所有逻辑都写在 `while(1)` 里排队执行，现在把不同功能拆成多个“任务函数”，由 RTOS 按优先级和周期调度。

本项目同时有 IMU DMA、ADC DMA、LCD 刷新、无线数据串口和无线调试串口。用 RTOS 拆开后，采样、算法、显示和通信之间不容易互相卡住。

### 14.1 CubeMX FreeRTOS 基础配置

在 `Middleware and Software Packs > FREERTOS` 中配置：

```text
Interface: CMSIS_V2
Kernel: FreeRTOS
USE_NEWLIB_REENTRANT: Enable
Heap Usage Scheme: heap_4
TOTAL_HEAP_SIZE: 24KB 起步，后续按实际内存占用调整
MINIMAL_STACK_SIZE: 256 words
configLIBRARY_MAX_SYSCALL_INTERRUPT_PRIORITY: 5
TICK_RATE_HZ: 1000
```

在 `System Core > SYS` 中设置：

```text
Timebase Source: TIM17
```

原因：FreeRTOS 使用 SysTick 作为系统节拍，HAL 的 timebase 建议改用 TIM17，避免 HAL_Delay 和 RTOS tick 互相影响。改成 TIM17 后必须在 NVIC 中开启 `TIM17 global interrupt`，优先级设为 15。

`TIM6` 原先的 100Hz 算法节拍不再启用中断，由 `SensorTask` 用 10ms 周期实现。

### 14.2 新手理解：任务是什么

一个任务可以理解成一个独立循环：

```c
void StartSensorTask(void *argument)
{
    for (;;)
    {
        // 做传感器采集
        osDelay(10);
    }
}
```

RTOS 会在多个任务之间切换。优先级高的任务更容易先运行，所以采样任务优先级要高，显示和日志优先级要低。

本项目的优先级原则：

```text
采样 > 算法/肌电处理 > 通信/状态 > 显示/调试日志
```

### 14.3 CubeMX 任务配置表

在 `FREERTOS > Tasks and Queues` 中添加以下任务：

| Task Name | Entry Function | Priority | Stack Size | 周期/触发 | 作用 |
|---|---|---:|---:|---|---|
| SensorTask | StartSensorTask | osPriorityHigh | 512 words | 10ms | 读取 IMU，启动 SPI1 DMA，等待 DMA 完成 |
| AlgoTask | StartAlgoTask | osPriorityAboveNormal | 1024 words | 收到 IMU 数据后触发 | 姿态解算、角度计算、动作识别、评分 |
| EmgTask | StartEmgTask | osPriorityAboveNormal | 512 words | 20ms | 处理 ADC DMA 肌电缓冲区，计算 RMS/包络/阈值 |
| WirelessTask | StartWirelessTask | osPriorityNormal | 512 words | 100ms 或事件触发 | USART1 数据上传、板间数据、手机命令 |
| UiTask | StartUiTask | osPriorityNormal | 384 words | 20ms | LED、蜂鸣器状态；PA12 按键只预留不处理 |
| DisplayTask | StartDisplayTask | osPriorityLow | 768 words | 100ms-200ms | LCD 刷新角度、次数、评分、状态 |
| DebugTask | StartDebugTask | osPriorityLow | 512 words | 100ms-500ms | USART2 输出调试日志、处理调试命令 |

说明：

- `SensorTask` 优先级最高，因为 IMU 100Hz 采样要稳定。
- `DisplayTask` 和 `DebugTask` 优先级最低，因为屏幕和日志慢一点没关系，不能影响采样。
- `AlgoTask` 栈给 1024 words，是因为姿态解算和动作识别可能会用到较多局部变量。
- 如果后续出现 HardFault 或任务异常，优先把相关任务栈加大一档。

### 14.4 信号量、队列和互斥锁配置

在 `FREERTOS > Tasks and Queues` 中添加同步对象。这里分三类：

```text
Binary Semaphore: 用来通知“某个事件发生了”
Message Queue: 用来在任务之间传递数据
Mutex: 用来保护共享资源，防止多个任务同时访问
```

#### 14.4.1 Binary Semaphore

本项目的二值信号量都用于 DMA 或硬件事件通知，所以初始值必须为 0。

CubeMX 中添加：

| Name | Type | Initial Count | 用途 |
|---|---|---:|---|
| imuDmaDoneSem | Binary Semaphore | 0 | SPI1 DMA 读取 IMU 完成后释放，唤醒 SensorTask |
| adcHalfCpltSem | Binary Semaphore | 0 | ADC DMA 半缓冲完成，可选，用于唤醒 EmgTask |
| adcCpltSem | Binary Semaphore | 0 | ADC DMA 满缓冲完成，可选，用于唤醒 EmgTask |

为什么初始值是 0：

```text
初始值 0: 任务启动后会等待，直到中断真正释放信号量
初始值 1: 任务启动后会立刻通过，可能误以为 DMA 已经完成
```

所以 DMA 完成类信号量不要设成 1。

如果 CubeMX 没有显示 Initial Count，生成后第一次使用前可以在任务开始时先尝试 `osSemaphoreAcquire(..., 0)` 清一次，或者确认生成代码里初始 count 为 0。

#### 14.4.2 Message Queue

消息队列用于任务之间传递结构体数据。CubeMX 中常见配置项是：

```text
Queue Name
Queue Size
Item Size
Allocation
```

建议添加：

| Name | Queue Size | Item Size | Allocation | 用途 |
|---|---:|---|---|---|
| imuFrameQueue | 4 | sizeof(IMU_Frame_t) | Dynamic 或 Static | SensorTask 把 IMU 数据发给 AlgoTask |
| rehabStateQueue | 2 | sizeof(Rehab_State_t) | Dynamic 或 Static | AlgoTask 把角度/评分状态发给 DisplayTask/WirelessTask，可选 |
| debugLogQueue | 8 | sizeof(DebugLog_t) 或 sizeof(char *) | Dynamic 或 Static | 其他任务把日志发给 DebugTask，可选 |

推荐先必须建：

```text
imuFrameQueue
Queue Size: 4
Item Size: sizeof(IMU_Frame_t)
```

`IMU_Frame_t` 可以后续在代码中定义，例如：

```c
typedef struct
{
    int16_t ax;
    int16_t ay;
    int16_t az;
    int16_t gx;
    int16_t gy;
    int16_t gz;
    uint32_t tick;
} IMU_Frame_t;
```

队列长度为什么是 4：

```text
SensorTask 每 10ms 产生 1 帧
AlgoTask 正常应及时消费
Queue Size = 4 可以缓存约 40ms 数据
```

如果队列满了，不建议阻塞 SensorTask 太久。SensorTask 发送队列时建议：

```c
osMessageQueuePut(imuFrameQueueHandle, &imu_frame, 0, 0);
```

最后一个参数 timeout 为 0，表示队列满了就丢弃本帧，不要卡住采样任务。

`debugLogQueue` 如果用字符串指针：

```text
Item Size: sizeof(char *)
```

如果用固定结构体：

```c
typedef struct
{
    uint16_t id;
    int32_t value1;
    int32_t value2;
} DebugLog_t;
```

则：

```text
Item Size: sizeof(DebugLog_t)
```

新手阶段可以先不建 `debugLogQueue`，直接让 DebugTask 低频主动打印关键状态，系统稳定后再加日志队列。

#### 14.4.3 Mutex

Mutex 用来保护共享外设或共享数据。它和 Binary Semaphore 不一样：Mutex 表示“资源锁”，初始状态应为可用。

CubeMX 中添加：

| Name | Type | Recursive | 用途 |
|---|---|---|---|
| uart1Mutex | Mutex | Disable | 保护 USART1 发送，避免多个任务同时发数据 |
| uart2Mutex | Mutex | Disable | 保护 USART2 调试输出，避免日志交叉 |
| spi3LcdMutex | Mutex | Disable | 保护 LCD SPI3 访问，可选 |
| rehabStateMutex | Mutex | Disable | 保护全局训练状态，可选 |

Mutex 不需要设置 Initial Count。创建成功后默认是“可获取”的状态。

使用原则：

```text
谁要用共享资源，谁先 osMutexAcquire()
用完立刻 osMutexRelease()
不要长时间持有 Mutex
不要在中断里获取 Mutex
```

USART2 打印示例：

```c
osMutexAcquire(uart2MutexHandle, osWaitForever);
printf("angle=%d score=%d\r\n", angle, score);
osMutexRelease(uart2MutexHandle);
```

LCD 刷新示例：

```c
osMutexAcquire(spi3LcdMutexHandle, osWaitForever);
LCD_DrawText(0, 0, "RUN");
osMutexRelease(spi3LcdMutexHandle);
```

注意：如果只有 DisplayTask 一个任务操作 LCD，可以先不建 `spi3LcdMutex`。如果后续 DebugTask 或其他任务也要画屏，再启用它。

#### 14.4.4 当前阶段最小推荐

如果你想先少配一点，最小集合是：

```text
Binary Semaphore:
  imuDmaDoneSem, Initial Count = 0

Message Queue:
  imuFrameQueue, Queue Size = 4, Item Size = sizeof(IMU_Frame_t)

Mutex:
  uart2Mutex
```

如果 ADC DMA 和 USART1 也开始接入，再加：

```text
adcHalfCpltSem, Initial Count = 0
adcCpltSem, Initial Count = 0
uart1Mutex
```

如果开始移植 LVGL 或多个任务访问 LCD，再加：

```text
spi3LcdMutex
```
### 14.5 各任务具体做什么

#### SensorTask

职责：每 10ms 读取一次 IMU，也就是 100Hz。

流程：

```text
1. 等待 10ms 周期
2. 拉低 IMU_CS
3. 调用 HAL_SPI_TransmitReceive_DMA()
4. 等待 imuDmaDoneSem，建议超时 2ms
5. 拉高 IMU_CS
6. 解析 ax, ay, az, gx, gy, gz
7. 通过 imuFrameQueue 发给 AlgoTask
```

伪代码：

```c
void StartSensorTask(void *argument)
{
    uint32_t tick = osKernelGetTickCount();

    for (;;)
    {
        tick += 10;

        HAL_GPIO_WritePin(IMU_CS_GPIO_Port, IMU_CS_Pin, GPIO_PIN_RESET);
        HAL_SPI_TransmitReceive_DMA(&hspi1, imu_tx_buf, imu_rx_buf, imu_len);

        if (osSemaphoreAcquire(imuDmaDoneSemHandle, 2) == osOK)
        {
            HAL_GPIO_WritePin(IMU_CS_GPIO_Port, IMU_CS_Pin, GPIO_PIN_SET);
            IMU_ParseFrame(imu_rx_buf, &imu_frame);
            osMessageQueuePut(imuFrameQueueHandle, &imu_frame, 0, 0);
        }
        else
        {
            HAL_GPIO_WritePin(IMU_CS_GPIO_Port, IMU_CS_Pin, GPIO_PIN_SET);
            imu_error_count++;
        }

        osDelayUntil(tick);
    }
}
```

注意：SensorTask 不做姿态解算，只负责稳定采样。

#### AlgoTask

职责：等待 IMU 数据，做姿态解算、角度计算、动作识别和评分。

流程：

```text
1. 等待 imuFrameQueue
2. 取出 IMU 数据
3. 姿态解算
4. 计算角度
5. 动作识别
6. 更新评分结果
7. 更新全局训练状态
```

伪代码：

```c
void StartAlgoTask(void *argument)
{
    IMU_Frame_t frame;

    for (;;)
    {
        if (osMessageQueueGet(imuFrameQueueHandle, &frame, NULL, osWaitForever) == osOK)
        {
            Attitude_Update(&frame);
            RehabAngle_Update();
            ActionDetect_Update();
            Score_Update();
        }
    }
}
```

#### EmgTask

职责：处理 ADC DMA 缓冲区，计算肌电参与状态。

ADC 采样由硬件自动完成：

```text
TIM3 -> ADC1 -> DMA -> emg_adc_buf
```

EmgTask 不需要每次启动 ADC，只需要定期处理缓冲区。

流程：

```text
1. 每 20ms 运行一次
2. 从 emg_adc_buf 取最近数据
3. 整流
4. 平滑
5. 计算 RMS 或平均幅值
6. 判断主动发力状态
```

#### WirelessTask

职责：USART1 数据通信。

用途：

```text
1. 上传训练数据
2. 接收手机命令
3. 接收或发送板间同步数据
```

建议发送频率：2Hz-5Hz。不要用 USART1 高频刷 IMU 原始数据。

#### DebugTask

职责：USART2 调试日志。

用途：

```text
1. printf 调试日志
2. 输出错误码
3. 临时修改阈值参数
```

建议只输出低频摘要，例如：

```text
angle=75, emg=1, score=86, imu_err=0
```

不要在高优先级任务里直接大量 printf。

#### DisplayTask

职责：LCD 显示刷新。

建议周期：100ms-200ms。

显示内容：

```text
当前模式
角度
EMG 状态
次数
评分
异常提示
```

注意：不要全屏高频刷新，显示任务优先级保持低。

#### UiTask

职责：LED、蜂鸣器和预留按键。

当前 PA12 只预留，不参与业务逻辑：

```text
PA12: GPIO_Input, Pull-Up, No EXTI
```

UiTask 当前只处理：

```text
LED_STATUS
BUZZER
```

后续如果启用 PA12，可以在 UiTask 中轮询消抖，不一定要用 EXTI。

### 14.6 中断回调怎么配合 RTOS

中断里不要做复杂计算。中断只做三类事：

```text
释放信号量
投递队列
置标志位
```

SPI1 DMA 完成回调示例：

```c
void HAL_SPI_TxRxCpltCallback(SPI_HandleTypeDef *hspi)
{
    if (hspi == &hspi1)
    {
        osSemaphoreRelease(imuDmaDoneSemHandle);
    }
}
```

ADC DMA 回调示例：

```c
void HAL_ADC_ConvHalfCpltCallback(ADC_HandleTypeDef *hadc)
{
    if (hadc == &hadc1)
    {
        osSemaphoreRelease(adcHalfCpltSemHandle);
    }
}

void HAL_ADC_ConvCpltCallback(ADC_HandleTypeDef *hadc)
{
    if (hadc == &hadc1)
    {
        osSemaphoreRelease(adcCpltSemHandle);
    }
}
```

重要：这些回调里调用了 RTOS API，所以对应中断优先级必须设置为 5 或更大的数字。

### 14.7 新手推荐调试顺序

不要一次性把所有任务都打开。建议按下面顺序逐步加：

1. 只创建 `DebugTask`，确认 USART2 能打印日志。
2. 创建 `SensorTask`，先用阻塞 SPI 读取 IMU `WHO_AM_I`。
3. 把 SensorTask 改成 SPI1 DMA 读取 IMU。
4. 加 `imuDmaDoneSem`，确认 DMA 完成后能唤醒 SensorTask。
5. 加 `imuFrameQueue` 和 `AlgoTask`。
6. 启动 TIM3 + ADC1 + DMA，加 `EmgTask`。
7. 加 `DisplayTask`，低频刷新 LCD。
8. 加 `WirelessTask`，用 USART1 发送训练结果。
9. 最后再处理 CST816D 触摸、PA12 按键等低优先级功能。

每加一个任务，都先观察：

```text
是否还在正常打印日志
IMU 100Hz 是否稳定
是否进入 HardFault
任务栈是否不足
```

如果出现不稳定，优先检查：

```text
中断优先级是否 >= 5
任务栈是否太小
是否在中断里 printf
是否在高优先级任务里长时间刷屏
```
## 15. 低功耗配置

MVP 演示阶段先不启用 Stop/Standby 低功耗模式，避免影响调试。

可先配置：

```text
PWR: 默认
Low Power Mode: Disable
```

后期续航优化：

- SYSCLK 从 160MHz 降到 80MHz。
- P169H002 LCD降低刷新频率到 5Hz-10Hz。
- 无线串口只在结果变化或训练结束时发送。
- 没有训练时降低 IMU ODR。

## 16. CubeMX 最小可用配置清单

第一版必须配置：

- SYS: Serial Wire
- RCC: 默认内部时钟或外部晶振
- SPI1: 本节点 IMU
- SPI2: 不启用，预留
- SPI3: P169H002 LCD 显示，ST7789T3
- ADC1: 肌电输入
- DMA: SPI1_RX 使用 GPDMA1 Channel 0、SPI1_TX 使用 GPDMA1 Channel 1、ADC1 Circular
- TIM6: 不启用算法中断，预留
- TIM3: 500Hz ADC 触发 TRGO / Update Event
- USART1: 无线数据串口接口，115200
- USART2: 无线调试串口接口，115200
- GPIO: IMU CS、LCD CS/DC/RST/BL、TP_RST/TP_INT、无线串口 EN/STATE 可选、PA12 按键预留、LED/蜂鸣器
- NVIC: SPI1 DMA=5、ADC DMA=6、USART1=7、USART2=8、TIM17=15；PA12 按键当前不启用 EXTI

## 17. 建议引脚命名

在 CubeMX 的 GPIO 页面中给引脚设置 User Label，后续代码更清晰：

```text
IMU_SCK         = PA5
IMU_MISO        = PA6
IMU_MOSI        = PA7
IMU_CS          = PA4
IMU_INT         = PC8，可选
LCD_SCL         = PC10
LCD_SDA         = PC12
LCD_SDO         = PC11，可选
LCD_CS          = PA15
LCD_DC          = PB8
LCD_RST         = PB9
LCD_BL          = PA8
TP_SCL          = PB6
TP_SDA          = PB7
TP_RST          = PC5
TP_INT          = PC4
KEY_RESERVED    = PA12
LED_STATUS      = PC6
BUZZER          = PB2
EMG_ADC         = PC0
WIRELESS_RXD    = PA9  // 接模块 RXD，STM32 USART1_TX
WIRELESS_TXD    = PA10 // 接模块 TXD，STM32 USART1_RX
WIRELESS_EN     = PB0，可选
WIRELESS_STATE  = PB1，可选
DBG_RXD         = PA2  // 接调试模块 RXD，STM32 USART2_TX
DBG_TXD         = PA3  // 接调试模块 TXD，STM32 USART2_RX
```

生成代码后可直接在程序中使用：

```c
HAL_GPIO_WritePin(IMU_CS_GPIO_Port, IMU_CS_Pin, GPIO_PIN_RESET);
HAL_GPIO_WritePin(IMU_CS_GPIO_Port, IMU_CS_Pin, GPIO_PIN_SET);
```

## 18. 生成代码后的初始化顺序

CubeMX 生成的 `main.c` 中建议保持以下初始化顺序：

```text
HAL_Init()
SystemClock_Config()
MX_GPIO_Init()
MX_DMA_Init()
MX_ADC1_Init()
MX_SPI1_Init()
MX_SPI3_Init()
MX_I2C1_Init()
MX_USART1_UART_Init()
MX_USART2_UART_Init()
MX_TIM3_Init()

应用层初始化:
  IMU_Init()
  LCD_Init()
  Touch_Init()，可选
  WirelessData_Init()
  DebugUart_Init()
  RehabAlgo_Init()

启动外设:
  osKernelInitialize()
  创建 RTOS 任务、队列、信号量
  HAL_ADC_Start_DMA()
  HAL_TIM_Base_Start(&htim3)
  HAL_UART_Receive_IT(&huart1, ...)
  HAL_UART_Receive_IT(&huart2, ...)
  osKernelStart()
```

注意：如果 ADC 由 TIM3 TRGO / Update Event 触发，需要先启动 ADC DMA，再启动 TIM3。SPI1 DMA 不在初始化阶段持续启动，而是在 `SensorTask` 每 10ms 发起一次 `HAL_SPI_TransmitReceive_DMA()`。FreeRTOS 启用后，`osKernelStart()` 之后不再返回主循环，业务逻辑放到任务里。

## 19. 调试顺序

不要一次性联调全部功能，建议按以下顺序验证：

1. 点灯和 USART2 printf 调试日志。
2. USART1 无线数据串口收发。
3. SPI1 阻塞方式读取本节点 IMU WHO_AM_I。
4. SPI1 DMA 方式连续读取 IMU 原始数据。
5. FreeRTOS `SensorTask` 10ms 周期是否稳定。
6. 本节点 IMU 100Hz 连续读取是否稳定。
7. ADC DMA 肌电采样波形是否变化。
8. LCD 显示文字。
9. USART1 无线数据串口发送训练结果。
10. USART2 无线调试串口输出角度、状态和错误码。
11. 姿态解算和角度计算。
12. 动作识别、评分和异常提醒。

## 20. 推荐通信与显示刷新频率

| 模块 | 频率 |
|---|---:|
| IMU 原始读取 | 100Hz |
| 姿态解算 | 100Hz |
| EMG ADC | 500Hz |
| EMG 特征更新 | 20Hz-50Hz |
| 动作识别 | 50Hz-100Hz |
| P169H002 LCD刷新 | 5Hz-10Hz |
| USART1 无线数据实时发送 | 2Hz-5Hz |
| USART1 无线数据结果发送 | 训练结束发送 |
| USART2 调试日志 | 2Hz-10Hz，按需开启 |

## 21. MVP 推荐最终配置摘要

```text
MCU: STM32U575RIT6
SYSCLK: 160MHz
IMU: SPI1, Mode 3, 8bit, Software NSS, PA4 CS GPIO, RX/TX DMA
Display: P169H002 LCD, SPI3, Mode 0, 8bit, Software NSS, ST7789T3, PA15 CS GPIO
EMG: ADC1 single channel, TIM3 TRGO / Update Event, 500Hz, DMA circular
Wireless Data UART: USART1, PA9/PA10, 115200, 8N1
Wireless Debug UART: USART2, PA2/PA3, 115200, 8N1
Timer:
  TIM6 = disabled/reserved, not algorithm tick
  TIM3 = 500Hz ADC trigger
GPIO:
  1 reserved key: PA12, GPIO_Input, no EXTI
  1 status LED
  1 buzzer or warning output
Interrupt:
  SPI1 RX DMA: GPDMA1 Channel 0, preemption priority 5
  SPI1 TX DMA: GPDMA1 Channel 1, preemption priority 5
  ADC DMA: preemption priority 6
  USART1: preemption priority 7
  USART2: preemption priority 8
  TIM17 HAL timebase: preemption priority 15
  PA12 key reserved, EXTI disabled
RTOS: Enable, CMSIS-RTOS v2
```

## 22. 关键注意事项

- FreeRTOS 下会调用 FromISR API 的中断优先级必须设置为 5 或更大的数字；不要把 SPI/ADC/UART 中断设为 0-4。
- SPI1 和 SPI3 使用软件片选：CubeMX 中关闭 Hardware NSS，CS 引脚按普通 GPIO_Output 配置，默认高电平；SPI1 DMA 完成前不要拉高 IMU_CS。
- 当前节点只接一颗 IMU；第二颗远端 IMU 建议由另一块 STM32U575RIT6 就近采集，再通过无线串口或其他通信方式同步数据。
- 本项目屏幕为 P169H002 LCD 触摸显示屏：ST7789T3 使用 SPI 显示接口，CST816D 使用 I2C 触摸接口，不按 I2C OLED 配置。
- 肌电模块输出电压必须在 STM32 ADC 输入范围内，不能超过 3.3V。
- 无线串口模块必须和 STM32 共地。
- USART2 是独立无线调试串口，建议只发低频摘要日志，不要在高优先级任务或中断里直接大量 printf。
- 显示刷新不要放在高优先级中断里，应在主循环低频刷新。
- 姿态解算和动作识别不要写在 TIM6 中断里，TIM6 中断只置标志位，主循环执行算法。
- 第一次联调时，先关闭显示屏大面积刷新，只打印传感器数据，确认采集稳定后再加 UI。

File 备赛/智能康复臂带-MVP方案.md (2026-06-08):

# AI-RehabBand 智能康复臂带 MVP 方案

## 项目定位

本版本以一个月左右的开发周期为边界，目标是做出一个能够稳定演示的训练评估与反馈型康复原型。系统以双 IMU 为运动感知主体，加入简化肌电采集，用于反映患者主动参与情况，在 STM32 平台上完成动作识别、角度计算、参与度评估、异常提醒和结果展示。

## 一、MVP 阶段解决的问题

脑卒中上肢康复训练中，常见问题并不只是动作有没有做出来，还包括动作是否标准、是否存在主动发力、训练过程是否安全可控。MVP 阶段聚焦以下四项能力：

1. 实时采集上臂与手腕运动数据。
2. 识别少量高相关上肢康复动作。
3. 计算肘关节角度、次数和基础训练评分。
4. 通过简化肌电信号判断主动参与程度。

## 二、MVP 功能边界

### 当前保留的功能

- 双 IMU 采集上臂和手腕姿态数据。
- 1 组简化肌电采集，用于主动参与判断。
- STM32 本地完成数据处理与训练逻辑。
- 实时计算肘关节角度。
- 识别 4 类基础上肢动作。
- 输出完成度、平稳度、参与度和综合评分。
- 提供训练引导、主动参与、异常提醒三种模式。
- 通过 OLED 和蓝牙输出训练结果。

### 当前不纳入 MVP 的功能

- 气动助力或被动牵引执行机构。
- 多通道肌电阵列。
- 压力阵列。
- 云端平台和医生端 Web。
- 临床量表映射。
- 复杂个性化处方系统。

当前阶段采用的策略是，在保留作品专业度的同时，把执行复杂度控制在可以按时完成的范围内。

## 三、现场演示目标

比赛现场应完成如下演示流程：

1. 用户佩戴上臂和手腕传感器，贴附肌电电极。
2. 设备开机，进入训练模式选择界面。
3. 用户选择指定动作并开始训练。
4. 系统实时显示当前动作、肘关节角度、肌电参与状态、动作次数和当前分数。
5. 训练结束后在本机显示本次结果，并通过蓝牙发送到手机端。

通过这个流程，作品能够形成完整的训练闭环，而不是停留在单纯的数据采集层面。

## 四、推荐硬件组成

| 模块 | 型号建议 | 数量 | 用途 |
|---|---|---|---|
| 主控 | STM32U575 开发板 | 1 | 数据处理、算法运行、显示与通信 |
| IMU 传感器 | 逐飞 IMU660RB（核心芯片 LSM6DSRTR） | 2 | 上臂与手腕姿态采集 |
| 肌电采集 | MyoWare 2.0 / ADS1292R 简化方案 | 1 组 | 主动参与检测 |
| 显示屏 | 0.96 寸 OLED（驱动IC是ST7789P3） | 1 | 显示动作、角度、状态与评分 |
| 蓝牙模块 | HM-10 / ESP32-C3 串口透传 | 1 | 手机通信 |
| 电池 | 500mAh 锂电池 | 1 | 便携供电 |
| 固定结构 | 臂带、表带、电极贴片、小外壳 | 1 套 | 佩戴与封装 |

### 选型说明

- 单主控架构更适合一个月周期开发。
- 双 IMU 仍然是作品的核心价值，用于关节相对运动分析。
- IMU 优先采用逐飞 `IMU660RB` 成品模块，减少底层硬件焊接和传感器调试成本。
- 肌电只做简化主动参与检测，不做复杂医学级分析。
- OLED 足够承载现场展示信息，开发成本低。

## 五、系统架构

```text
上臂 IMU ─┐
手腕 IMU ─┼─> STM32U575 ─> 姿态解算/动作识别 ─> 评分计算 ─> OLED
肌电采集 ─┘                                           │
                                                     └─> 蓝牙发送到手机
```

### 数据流

```text
传感器采集 -> 数据滤波 -> 姿态解算 -> 相对姿态求角度 -> 肌电参与判定 -> 动作识别 -> 评分输出
```

## 六、软件功能拆解

### 1. 传感器采集

- IMU 采样频率：50Hz-100Hz。
- 肌电采样频率：建议 200Hz-500Hz，MVP 可先做包络或阈值判定。
- 采集内容：
  - 上臂 IMU：ax, ay, az, gx, gy, gz
  - 手腕 IMU：ax, ay, az, gx, gy, gz
  - 肌电信号：emg_raw / emg_level

### 2. 姿态解算与角度计算

- 使用 Madgwick 或互补滤波进行姿态估计。
- 结合上下肢相对姿态计算肘关节近似角度。
- 提供动作幅度、平均角度、最大角度等训练指标。

### 3. 动作识别

MVP 只保留最适合展示、最容易做稳的 4 类动作：

| 编号 | 动作 | 主要依据 |
|---|---|---|
| 0 | 肘关节弯曲 | 关节角度周期性变化 |
| 1 | 手臂外展 | 上臂姿态抬升明显 |
| 2 | 前臂转动 | 陀螺仪角速度变化明显 |
| 3 | 肩上举 | 上臂大幅上抬 |

### 4. 肌电参与判定

MVP 阶段不追求复杂肌电分类，只完成以下能力：

- 对肌电原始信号做整流和平滑。
- 提取简单幅值特征或 RMS 值。
- 根据阈值判断用户是否存在主动发力。
- 将主动参与结果映射到训练评分中。

### 5. 评分机制

建议采用可解释的基础评分：

```text
总分 = 完成度 * 0.5 + 平稳度 * 0.25 + 节奏达标 * 0.1 + 主动参与度 * 0.15
```

评分项说明：

- 完成度：动作幅度是否达到目标区间。
- 平稳度：训练过程中抖动和突变是否过大。
- 节奏达标：动作频率是否接近预设节奏。
- 主动参与度：训练时是否出现有效肌电激活。

### 6. 本地显示与手机端同步

OLED 推荐显示内容：

- 当前模式
- 当前动作
- 实时角度
- EMG 状态
- 当前次数
- 当前评分

手机端推荐保留：

1. 设备连接页
2. 本次训练结果页
3. 历史训练记录页

## 七、训练模式设计

### 模式一：引导训练模式

- 适用场景：动作学习、重复训练。
- 功能：给出目标动作、节奏和目标角度范围。
- 输出：次数、达标率、平均角度、平均分数。

### 模式二：主动参与模式

- 适用场景：恢复期训练。
- 功能：在动作检测基础上叠加肌电参与判定。
- 输出：主动参与次数、参与度评分、综合训练评分。

### 模式三：异常提醒模式

- 适用场景：动作速度过快、抖动过大、角度超限。
- 功能：检测异常角速度或异常姿态变化，并提示减速或暂停。
- 输出：异常次数、异常类型、训练中断提醒。

## 八、算法实现策略

### 第一阶段：规则法优先

在一个月周期内，优先使用规则法和阈值法：

- 肘关节弯曲：角度在阈值区间内往复变化。
- 手臂外展：上臂抬升角度超过阈值。
- 前臂转动：特定轴角速度呈往复变化。
- 主动参与判定：EMG 包络值超过阈值并维持一定时间。

### 第二阶段：轻量 AI 预留

如果前述部分提前稳定，可补充轻量模型：

- 输入：1 秒窗口特征。
- 特征：IMU 时域特征 + 简化 EMG 幅值特征。
- 模型：小型全连接网络或 1D CNN。
- 目标：模型体积控制在 50KB 左右。

## 九、验收指标

| 指标 | 目标值 | 说明 |
|---|---|---|
| 动作识别准确率 | >= 85% | 4 类基础动作 |
| 主动参与判定成功率 | >= 80% | 基于阈值法 |
| 角度测量重复性误差 | <= 5 deg | 同一动作多次测量 |
| 系统响应延迟 | <= 300ms | 从动作发生到屏幕刷新 |
| 连续运行时间 | >= 2h | 实测结果 |
| 蓝牙传输成功率 | >= 95% | 训练结果稳定发送 |

建议至少准备以下实验结果：

1. 动作识别结果统计表。
2. 肘关节角度变化曲线。
3. EMG 激活示意曲线。
4. 单次训练结果示例。

## 十、4 周开发安排

### 第 1 周

- 打通双 IMU 通信。
- 完成简化肌电采集验证。
- 完成 OLED 显示和蓝牙数据发送。

### 第 2 周

- 完成姿态解算。
- 完成肘关节角度计算。
- 完成 2-3 类动作规则识别。
- 完成基础肌电阈值判定。

### 第 3 周

- 完成评分机制。
- 完成训练模式切换逻辑。
- 完成手机端基础展示。
- 开始采集测试数据。

### 第 4 周

- 完成联调。
- 进行准确率、延迟、续航和参与判定测试。
- 修复关键误判。
- 整理答辩材料和演示视频。

## 十一、人员分工建议

| 成员 | 主要工作 |
|---|---|
| A | STM32 驱动、IMU/EMG 采集、姿态解算 |
| B | 动作识别、EMG 判定、评分算法、测试数据整理 |
| C | OLED 界面、蓝牙通信、手机端展示、文档和答辩材料 |

## 十二、当前版本的创新点定义

1. 双 IMU 相对姿态测角，用于上肢关节运动评估。
2. 姿态信息与简化肌电参与信号结合，用于反映主动参与程度。
3. 本地实时训练评估与异常提醒，不依赖云端完成核心闭环。

## 十三、结论

当前版本更适合定位为训练评估与反馈型智能康复臂带。通过双 IMU 和简化肌电采集，系统能够在有限周期内完成动作识别、角度计算、主动参与评估和异常提醒，既避免了执行助力设备的高风险，也保留了康复场景下较强的专业性和展示价值。

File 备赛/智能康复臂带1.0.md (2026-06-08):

# AI-RehabBand 智能康复臂带 - 完整实施方案

## 📋 项目概述

**项目名称**：智能康复臂带 —— 脑卒中患者上肢运动精确评估

**核心目标**：为脑卒中患者提供AI驱动的康复动作识别和进度评估系统

**设计理念**：采用上臂+手腕双传感器方案，通过相对姿态计算实现关节角度精确测量

---

基于双STM32U575的智能康复评估与康复动作识别臂带

本作品基于双 STM32U575 同构双主控平台，面向脑卒中患者上肢康复场景，采用上臂 + 手腕双 6 轴 IMU实现肘关节角度精准解算，通过STM32CubeAI 部署＜50KB 轻量 CNN 模型，离线识别 6 类康复动作，以 “完成度 + 平稳度 + 频率” 三维指标量化康复质量。系统集成双屏显示、离线语音交互、蓝牙 App 同步，实现训练实时反馈、数据追溯与进度评估，解决传统康复评估主观、居家训练缺乏指导的痛点，具备便携、低功耗、高隐私、高准确率（＞90%）特点，可广泛用于家庭与临床康复辅助。

## 🎯 三个方案对比

| 对比项 | 方案A（推荐） | 方案B | 方案C |
|---|---|---|---|
| 硬件 | 双主控+双屏幕 | 开发板+简化PCB | 完整自制PCB |
| 主控 | 双 STM32U575 | U5单主控 | U5单主控 |
| 传感器数 | 2个(6轴) | 3个(6轴+气压) | 3个 |
| 佩戴方式 | 臂带+手表 | 臂带+手表 | 一体化智能臂带 |
| 显示 | TFT+OLED双屏 | 单TFT屏 | 单TFT屏 |
| 外观设计 | 原型阶段 | 定制外壳 | 工业设计 |
| AI算法 | 简单CNN<50KB | 多模型融合 | 医学特异AI |
| App | Flutter简单UI | Flutter完整功能 | Flutter+Web |
| 续航 | 6小时 | 3天 | 5天 |
| 实现难度 | ⭐⭐⭐⭐ | ⭐⭐⭐ | ⭐⭐⭐⭐⭐ |
| 工作量 | 5-7个月 | 4-6个月 | 6-8个月 |
| 省赛获奖概率 | 90% | 85% | 95% |
| 国赛获奖概率 | 75% | 70% | 85% |

---

## 💰 模块

| 项目 | 单价 | 数量 |
|---|---|---|
| stm32U5 | NUCLEO-U575开发板 | 2 |
| 姿态传感器 | LSM6DSV16X传感器模块 | 2 |
| 气压传感器 | LPS22DF气压传感器 | 1 |
| TFTLCD屏幕 | 正点原子3.5寸触摸屏 | 1 |
| OLED屏幕 | 0.96寸 128×64 | 1 |
| 语音模块 | ASRPro2 | 1 |
| 无线模块 | nRF24L01+ | 2 |
| 蓝牙模块 | HM-10蓝牙模块 | 1 |
| 锂电池+充电管理 |  | 1 |
| 魔术贴绑带+表带 |  | 1 |
| PCB制造+焊接 |  | 1 |
| 其他元器件 |  | 1 |

---

## 📐 方案框架总结

### 一、系统架构

**三层架构**：

- **感知层**：上臂传感器 + 手腕传感器（双6轴IMU）
- **计算层**：上臂端（U575）+ 手腕端（U575）同构双主控
- **应用层**：TFTLCD显示 + OLED显示 + App + 语音

**数据流**：

```
传感器 → 无线传输 → 姿态融合 → 特征提取 → AI推理 → 评分计算 → 显示/播报
```

### 二、硬件组成

| 位置 | 硬件 | 数量 | 功能 |
| --- | --- | ---- | --- |
| 上臂端 | NUCLEO-U575 | 1 | 主控、无线发送、TFT显示、局部预处理 |
| 手腕端 | NUCLEO-U575 | 1 | 主控、AI推理、蓝牙通信、评分反馈 |
| 传感器 | LSM6DSV16X | 2 | 上臂+手腕6轴IMU |
| 无线 | nRF24L01+ | 2 | 双端通信 |
| 显示 | TFTLCD 3.5" + OLED 0.96" | 2 | 双屏显示 |
| 语音 | ASRPro2 | 1 | 语音播报+控制 |
| 通信 | HM-10 | 1 | App通信 |

### 三、软件架构

**上臂端任务**（FreeRTOS）：

- 传感器采集任务（100Hz）
- 无线发送任务（100Hz）
- TFTLCD显示任务（10Hz）

**手腕端任务**（FreeRTOS）：

- 无线接收任务（100Hz）
- 姿态融合任务（100Hz）
- 特征提取任务（10Hz）
- AI推理任务（10Hz）
- 评分计算任务（10Hz）
- OLED显示任务（10Hz）
- 蓝牙发送任务（10Hz）

### 四、核心算法

| 算法 | 功能 |
| --- | --- |
| Madgwick AHRS | 姿态融合，获取四元数 |
| 相对姿态计算  | 双传感器计算肘关节角度（0°-180°）  |
| 特征提取 | 时域+频域+角度特征（100维） |
| CNN分类 | 6个康复动作识别（准确率>90%） |
| 评分算法 | 完成度×60% + 平稳度×30% + 频率×10% |

### 五、康复动作

| 编号 | 动作 | 评估指标 |
| ---- | --- | --- |
| 0 | 前臂转动 | 陀螺仪Y轴周期性变化 |
| 1 | 手臂外展 | 上臂Z轴上升幅度 |
| 2 | 肘关节弯曲 | 肘关节角度范围（40°-150°） |
| 3 | 腕关节旋转 | 手腕陀螺仪高频变化 |
| 4 | 肩上举 | 上臂Z轴持续上升 |
| 5 | 步行平衡 | 上臂X轴周期性摇晃 |

### 六、交互设计

| 反馈方式 | 位置 | 内容 |
| --- | --- | --- |
| TFTLCD | 上臂端 | 主界面、训练曲线、历史记录 |
| OLED | 手腕端 | 实时角度、当前动作、评分 |
| 语音 | 全局 | 播报分数、鼓励语、语音控制 |
| 振动 | 全局 | 评分<60%提醒 |
| App | 手机端 | 实时数据、历史趋势、康复报告 |

### 七、实施阶段

| 阶段 | 时间 | 内容 |
| --- | --- | --- |
| 第1阶段 | 第1-2周 | 硬件采购、原型验证 |
| 第2阶段 | 第3-6周 | 固件开发、AI训练 |
| 第3阶段 | 第5-6周 | App开发、系统联调  |

### 八、核心创新点

1. **双传感器关节角度计算** - 通过上臂+手腕相对姿态精确获取肘关节角度
2. **康复进度量化** - 完成度×60% + 平稳度×30% + 频率×10%
3. **智能反馈** - 评分<60%振动提醒，>80%语音鼓励
4. **本地AI推理** - STM32CubeAI部署轻量CNN（<50KB），隐私安全
5. **双屏交互** - TFT主显示+OLED实时数据显示
6. **语音交互** - ASRPro2离线语音控制+播报

## 🎯 上肢运动精确评估方法

### 1. 双主控硬件架构

```
┌─────────────────────────────────────────────────────────┐
│                      上臂端 (NUCLEO-U575)                 │
│  ┌─────────┐  ┌─────────┐  ┌─────────┐                 │
│  │传感器采集│  │无线发送 │  │TFTLCD   │                 │
│  │(100Hz)  │  │nRF24L01 │  │3.5寸屏  │                 │
│  └─────────┘  └─────────┘  └─────────┘                 │
└────────────────────────┬────────────────────────────────┘
                         │ 无线 (nRF24L01+)
                         ↓
┌─────────────────────────────────────────────────────────┐
│                      手腕端 (NUCLEO-U575)                 │
│  ┌─────────┐  ┌─────────┐  ┌─────────┐  ┌─────────┐   │
│  │无线接收 │  │AI推理   │  │OLED显示 │  │蓝牙通信 │   │
│  │(100Hz)  │  │(10Hz)   │  │(10Hz)   │  │(10Hz)   │   │
│  └─────────┘  └─────────┘  └─────────┘  └─────────┘   │
└─────────────────────────────────────────────────────────┘
                         │
                    ┌────┴────┐
                    │ 手机App │
                    │ 数据显示 │
                    └─────────┘
```

### 2. 屏幕分工设计

| 屏幕 | 位置 | 分辨率 | 功能 | 功耗 |
|-----|---|---|---|---|
| TFTLCD 3.5" | 上臂 | 320×480 | 主界面、训练曲线、历史记录、设置 | 高（背光200mA） |
| OLED 0.96" | 手腕 | 128×64 | 实时角度、当前动作、实时评分 | 低（<10mA） |

**显示内容分工**：
```
上臂TFTLCD：                    手腕OLED：
┌─────────────────────┐       ┌─────────┐
│  AI-RehabBand       │       │ 120°    │ ← 实时角度
├─────────────────────┤       │ 肘弯    │ ← 当前动作
│ [开始训练]           │       │ 85      │ ← 实时评分
│ [历史记录]           │       └─────────┘
│ [系统设置]           │
└─────────────────────┘
```

### 3. 双主控通信

**无线模块**：nRF24L01+（2.4GHz，增强版）

```c
// 上臂端 - 发送传感器数据
void nrfSendTask(void *pvParameters) {
    TickType_t xLastWakeTime = xTaskGetTickCount();
    while(1) {
        SensorData_t data = {
            .upper_arm = readUpperArmSensor(),
            .wrist = readWristSensor(),
            .timestamp = xTaskGetTickCount()
        };

        // 发送数据包（100Hz）
        nRF24_TxPacket(&data, sizeof(data));

        vTaskDelayUntil(&xLastWakeTime, pdMS_TO_TICKS(10));
    }
}

// 手腕端 - 接收数据
void nrfRxTask(void *pvParameters) {
    SensorData_t data;
    while(1) {
        if (nRF24_RxPacket(&data, sizeof(data)) == RX_OK) {
            // 推送到处理队列
            xQueueSend(sensorQueue, &data, 0);
        }
    }
}

// 数据包格式
typedef struct {
    uint8_t upper_arm[6];   // 上臂传感器6轴
    uint8_t wrist[6];       // 手腕传感器6轴
    uint32_t timestamp;
} SensorData_t;
```

**通信参数**：
| 参数 | 值 |
|-----|-----|
| 频率 | 2.4GHz |
| 速率 | 2Mbps |
| 发射功率 | 0dBm |
| 传输距离 | 10米 |
| 延迟 | <5ms |

### 4. 功耗管理

```c
typedef enum {
    MODE_ACTIVE,     // 160MHz, 150mA - 训练时
    MODE_NORMAL,     // 80MHz, 80mA   - 待机时
    MODE_LOW_POWER,  // 16MHz, 20mA   - 息屏时
    MODE_SLEEP,      // STOP模式, 1µA - 关机时
} PowerMode_t;

// 上臂端功耗管理
void upperArmPowerManage(void) {
    if (isTraining) {
        setPowerMode(MODE_ACTIVE);
        TFT_Backlight(100);  // 背光最亮
    } else if (lastTouchTime > 30000) {
        TFT_Backlight(20);   // 背光变暗
    } else if (lastTouchTime > 60000) {
        TFT_DisplayOff();    // TFT息屏
        setPowerMode(MODE_LOW_POWER);
    } else {
        setPowerMode(MODE_SLEEP);  // 长时间无操作休眠
    }
}

// 手腕端功耗管理（OLED息屏）
void wristPowerManage(void) {
    if (isTraining) {
        setPowerMode(MODE_ACTIVE);
        OLED_Wakeup();  // OLED唤醒
    } else if (lastTouchTime > 30000) {
        OLED_Sleep();   // OLED息屏（低功耗）
        setPowerMode(MODE_LOW_POWER);
    } else {
        setPowerMode(MODE_SLEEP);
    }
}

// 续航估算
// 上臂端：250mAh电池
// - 训练模式（10分钟/天）：150mA × 10/60 = 25mAh
// - 待机模式（8小时/天）：80mA × 8 = 640mAh
// - 息屏模式（15小时/天）：20mA × 15 = 300mAh
// 日总耗电：~965mAh → 续航约6小时（需加大电池）

// 推荐：上臂端用1000mAh电池，手腕端用500mAh电池
```

### 5. 双屏幕显示驱动

```c
// 上臂TFTLCD显示任务
void vUpperDisplayTask(void *pvParameters) {
    TickType_t xLastWakeTime = xTaskGetTickCount();
    while(1) {
        ScreenType_t screen = getCurrentScreen();

        switch(screen) {
            case SCREEN_HOME:
                showHomeScreen();
                break;
            case SCREEN_TRAINING:
                showTrainingScreen();
                break;
            case SCREEN_HISTORY:
                showHistoryScreen();
                break;
            case SCREEN_SETTINGS:
                showSettingsScreen();
                break;
        }

        vTaskDelayUntil(&xLastWakeTime, pdMS_TO_TICKS(100));
    }
}

// 手腕OLED显示任务（实时信息）
void vWristDisplayTask(void *pvParameters) {
    TickType_t xLastWakeTime = xTaskGetTickCount();
    while(1) {
        // 显示实时角度（大字体）
        OLED_ShowNum(0, 0, (int)currentAngle, 3, 16);  // 16号字体

        // 显示当前动作
        const char* actionNames[] = {"前臂转", "外展", "肘弯", "腕转", "肩上举", "步行"};
        OLED_ShowString(0, 20, actionNames[currentAction]);

        // 显示实时评分
        OLED_ShowNum(80, 0, (int)currentScore, 3, 16);

        // 息屏模式
        if (displayState == STATE_SLEEP) {
            OLED_Clear();
        }

        vTaskDelayUntil(&xLastWakeTime, pdMS_TO_TICKS(100));
    }
}
```

### 2. 双传感器数据采集（100Hz）

```c
// 传感器数据结构
typedef struct {
    float accel[3];    // 加速度 (g)
    float gyro[3];     // 角速度 (°/s)
} IMUData_t;

// 采集任务
void vSensorTask(void *pvParameters) {
    TickType_t xLastWakeTime = xTaskGetTickCount();
    while(1) {
        IMUData_t upper_arm, wrist;

        // 读取上臂传感器 (I2C地址0x6A)
        LSM6DSV16X_Read(0x6A, upper_arm.accel, upper_arm.gyro);

        // 读取手腕传感器 (I2C地址0x6B)
        LSM6DSV16X_Read(0x6B, wrist.accel, wrist.gyro);

        // 推送到数据缓冲
        pushToBuffer(&upper_arm, &wrist);

        vTaskDelayUntil(&xLastWakeTime, pdMS_TO_TICKS(10));  // 10ms = 100Hz
    }
}
```

### 3. 姿态融合算法（AHRS）

使用Madgwick算法融合加速度+陀螺仪数据，获取四元数姿态：

```c
// 四元数姿态
float q[4] = {1, 0, 0, 0};  // 初始姿态

// Madgwick姿态更新
void updateAttitude(float ax, float ay, float az,
                    float gx, float gy, float gz) {
    float dt = 0.01f;  // 10ms

    // 归一化加速度
    float norm = sqrtf(ax*ax + ay*ay + az*az);
    ax /= norm; ay /= norm; az /= norm;

    // 四元数更新
    float q0 = q[0], q1 = q[1], q2 = q[2], q3 = q[3];

    float f1 = 2*(q1*q3 - q0*q2) - ax;
    float f2 = 2*(q0*q1 + q2*q3) - ay;
    float f3 = 2*(0.5 - q1*q1 - q2*q2) - az;

    // 梯度下降优化（简化版）
    float Jt[3][4];
    Jt[0][0] = -2*q2; Jt[0][1] = 2*q3; Jt[0][2] = -2*q0; Jt[0][3] = 2*q1;
    Jt[1][0] = 2*q1;  Jt[1][1] = 2*q0;  Jt[1][2] = 2*q3;  Jt[1][3] = 2*q2;
    Jt[2][0] = 0;     Jt[2][1] = -4*q1; Jt[2][2] = -4*q2; Jt[2][3] = 0;

    // 更新四元数
    q[0] += 0.5 * (-q1*gx - q2*gy - q3*gz) * dt;
    q[1] += 0.5 * ( q0*gx + q2*ay - q3*az) * dt;
    q[2] += 0.5 * (-q0*gy + q1*az + q3*gx) * dt;
    q[3] += 0.5 * ( q0*az - q1*ay + q2*gx) * dt;

    // 归一化
    norm = sqrtf(q[0]*q[0] + q[1]*q[1] + q[2]*q[2] + q[3]*q[3]);
    q[0] /= norm; q[1] /= norm; q[2] /= norm; q[3] /= norm;
}
```

### 4. 相对姿态计算（核心创新）

通过两个传感器的四元数计算肘关节角度：

```c
// 四元数乘法
void quatMultiply(float* a, float* b, float* result) {
    result[0] = a[0]*b[0] - a[1]*b[1] - a[2]*b[2] - a[3]*b[3];
    result[1] = a[0]*b[1] + a[1]*b[0] + a[2]*b[3] - a[3]*b[2];
    result[2] = a[0]*b[2] - a[1]*b[3] + a[2]*b[0] + a[3]*b[1];
    result[3] = a[0]*b[3] + a[1]*b[2] - a[2]*b[1] + a[3]*b[0];
}

// 四元数求共轭
void quatConjugate(float* q, float* result) {
    result[0] = q[0];
    result[1] = -q[1];
    result[2] = -q[2];
    result[3] = -q[3];
}

// 计算肘关节角度
float calculateElbowAngle(float* q_upper, float* q_wrist) {
    // q_relative = q_wrist * conjugate(q_upper)
    float q_conj[4], q_rel[4];
    quatConjugate(q_upper, q_conj);
    quatMultiply(q_wrist, q_conj, q_rel);

    // 四元数转欧拉角（Pitch即为肘关节屈伸角度）
    float pitch = asinf(2*(q_rel[0]*q_rel[2] - q_rel[3]*q_rel[1]));
    float angle = pitch * 180.0f / 3.14159f;

    // 归一化到 0°-180° 范围
    if (angle < 0) angle += 360;
    if (angle > 180) angle = 360 - angle;

    return angle;  // 0°=伸直, 150°=完全弯曲
}
```

### 5. 特征提取（1秒窗口）

每1秒提取一次特征向量：

| 特征类型 | 特征名 | 计算方法 |
|---|---|---|
| 时域 | 均值 | mean(accel_x) |
| 时域 | 方差 | var(accel_x) |
| 时域 | 峰值 | max(abs(accel_x)) |
| 时域 | 峰峰值 | max - min |
| 时域 | 均方根 | RMS(accel_x) |
| 频域 | FFT低频能量 | sum(FFT[0:10]) |
| 频域 | FFT中频能量 | sum(FFT[10:30]) |
| 频域 | FFT高频能量 | sum(FFT[30:50]) |
| 角度 | 关节角度均值 | mean(elbow_angle) |
| 角度 | 关节角度范围 | max - min |

**特征向量维度**：约100维

### 6. AI动作分类

```c
// 6个康复动作
typedef enum {
    ACTION_FOREARM_ROT,   // 前臂转动
    ACTION_ARM_ABDUCTION, // 手臂外展
    ACTION_ELBOW_FLEX,    // 肘关节弯曲
    ACTION_WRIST_ROT,     // 腕关节旋转
    ACTION_SHOULDER_LIFT, // 肩上举
    ACTION_WALKING        // 步行平衡
} ActionType_t;

// AI推理
void vAITask(void *pvParameters) {
    TickType_t xLastWakeTime = xTaskGetTickCount();
    while(1) {
        float features[100];
        float output[6];

        // 从缓冲提取特征
        extractFeatures(features, 100);

        // Edge Impulse模型推理
        ei_classifier_run(features, output);

        // 找最大概率的动作
        int best_action = argmax(output, 6);

        // 置信度阈值判断
        if (output[best_action] > 0.7) {
            current_action = best_action;
            calculateScore(best_action);
        }

        vTaskDelayUntil(&xLastWakeTime, pdMS_TO_TICKS(100));  // 10Hz
    }
}
```

### 7. AI模型训练完整流程

#### 7.1 数据采集

**采集设备**：
- NUCLEO-U575ZI-Q开发板×2
- 2个LSM6DSV16X传感器（上臂+手腕）
- 蓝牙模块连接电脑

**采集步骤**：
```
1. 烧录数据采集程序到开发板
2. 打开串口助手（如SSCOM）
3. 佩戴传感器：
   - 上臂传感器：绑在大臂中段
   - 手腕传感器：戴在手腕（手表位置）
4. 做标准动作，每个动作重复10次
5. 每次动作持续5秒
6. 串口输出CSV数据，保存到文件
```

**采集程序**：
```c
// 数据采集模式（100Hz）
void vDataCollectionMode(void) {
    while(1) {
        IMUData_t upper_arm, wrist;
        LSM6DSV16X_Read(0x6A, upper_arm.accel, upper_arm.gyro);
        LSM6DSV16X_Read(0x6B, wrist.accel, wrist.gyro);

        // 串口输出CSV格式
        printf("%.2f,%.2f,%.2f,%.2f,%.2f,%.2f,",
               upper_arm.accel[0], upper_arm.accel[1], upper_arm.accel[2],
               upper_arm.gyro[0], upper_arm.gyro[1], upper_arm.gyro[2]);
        printf("%.2f,%.2f,%.2f,%.2f,%.2f,%.2f\n",
               wrist.accel[0], wrist.accel[1], wrist.accel[2],
               wrist.gyro[0], wrist.gyro[1], wrist.gyro[2]);

        vTaskDelay(pdMS_TO_TICKS(10));  // 100Hz
    }
}
```

**数据量要求**：
| 动作 | 样本数 | 每样本时长 | 总时长 |
|-----|---|---|---|
| 前臂转动 | 20 | 5秒 | 100秒 |
| 手臂外展 | 20 | 5秒 | 100秒 |
| 肘关节弯曲 | 20 | 5秒 | 100秒 |
| 腕关节旋转 | 20 | 5秒 | 100秒 |
| 肩上举 | 20 | 5秒 | 100秒 |
| 步行平衡 | 20 | 5秒 | 100秒 |
| **合计** | **120** | - | **600秒** |

**CSV文件格式**：
```csv
ax1,ay1,az1,gx1,gy1,gz1,ax2,ay2,az2,gx2,gy2,gz2,label
0.01,0.98,0.12,0.5,1.2,0.3,0.02,0.99,0.11,0.4,1.1,0.2,0
0.02,0.97,0.13,0.6,1.3,0.4,0.03,0.98,0.12,0.5,1.2,0.3,0
...
```

#### 7.2 Edge Impulse模型训练

**步骤1：创建项目**
1. 访问 https://edgeimpulse.com
2. 注册账号并登录
3. 点击 "Create new project"
4. 项目名称："AI-RehabBand"
5. 选择 "Device type" → "STM32"

**步骤2：上传数据**
1. 点击 "Data acquisition"
2. 点击 "Upload data"
3. 选择所有CSV文件
4. 设置Label（标签）格式：第13列作为标签
5. 自动分割为训练集(80%)和测试集(20%)

**步骤3：设计特征提取**
1. 点击 "Impulse design"
2. 添加 "Processing Block" → "Raw Data"
3. 添加 "Learning Block" → "Classification (Keras)"
4. 设置窗口大小：1000ms（1秒）
5. 设置窗口增加：200ms（每200ms提取一次特征）

**步骤4：训练模型**
1. 点击 "Neural Network" → "Training"
2. 配置模型结构：
```
输入层: 100个特征
Dense层: 64神经元, ReLU
Dense层: 32神经元, ReLU
Dense层: 6神经元, Softmax  (6个动作类别)
```
3. 设置训练参数：
   - Epochs: 100
   - Batch size: 32
   - Learning rate: 0.005
4. 点击 "Start training"

**步骤5：验证模型**
1. 点击 "Model testing"
2. 点击 "Classify all"
3. 查看准确率（目标>90%）
4. 查看混淆矩阵

**步骤6：导出模型**
1. 点击 "Deployment"
2. 选择 "STM32CubeAI" → "C++ Library"
3. 点击 "Build"
4. 下载ZIP文件

#### 7.3 集成到STM32项目

**步骤1：添加库文件**
```
下载的ZIP文件包含：
├── edge-impulse-sdk/
├── model-parameters/
├── tflite-model/
└── ei_*.h
```

**步骤2：复制到项目**
```
STM32项目/
├── Core/
│   ├── Inc/
│   │   ├── edge-impulse-sdk/
│   │   ├── model-parameters/
│   │   └── tflite-model/
│   └── Src/
│       └── main.c
└── Drivers/
```

**步骤3：调用推理**
```c
#include "edge-impulse-sdk/classifier/ei_run_classifier.h"

float features[100];
float output[6];
EI_IMPULSE_ERROR res;

// 提取特征（需与Edge Impulse设置一致）
extractFeatures(features, 100);

// 运行推理
res = ei_run_classifier(features, 100, output, false);

// 检查结果
if (res == EI_IMPULSE_OK) {
    int best_class = argmax(output, 6);
    float confidence = output[best_class];
    if (confidence > 0.7) {
        // 识别成功
    }
}
```

**步骤4：性能优化**
```c
// 在edge_configure.h中优化
#define EI_CLASSIFIER_TFLITE_ENABLE_HEIRARCHICAL_FIFO 1
#define EI_CLASSIFIER_TFLITE_ARENA_SIZE_KB 64

// 推理时间目标：<50ms
```

#### 7.4 模型评估指标

| 指标 | 目标值 | 说明 |
|-----|---|---|
| 准确率 | >90% | 正确分类样本数/总样本数 |
| 推理时间 | <50ms | 单次推理耗时 |
| 模型大小 | <50KB | 存储占用 |
| 内存占用 | <64KB | RAM占用 |

### 7.5 康复动作识别完整流程

```
┌──────────┐    ┌──────────┐    ┌──────────┐    ┌──────────┐
│ 传感器   │ →  │ 特征提取 │ →  │ AI模型   │ →  │ 动作输出  │
│ 数据     │    │          │    │ 推理     │    │          │
└──────────┘    └──────────┘    └──────────┘    └──────────┘
```

#### 7.5.1 原始数据采集

**双传感器数据**（100Hz采样）：
```
上臂传感器：ax, ay, az, gx, gy, gz  （6个值）
手腕传感器：ax, ay, az, gx, gy, gz  （6个值）
```

**1秒窗口数据量** = 100Hz × 1秒 × 12个值 = 1200个数据点

#### 7.5.2 特征提取

从原始数据提取100维特征：

| 特征类型 | 特征名 | 计算方法 |
|---|---|---|
| 时域 | 均值 | mean(ax) |
| 时域 | 方差 | var(ax) |
| 时域 | 标准差 | std(ax) |
| 时域 | 峰值 | max(ax) |
| 时域 | 峰峰值 | max(ax) - min(ax) |
| 时域 | 偏度 | skewness(ax) |
| 时域 | 峰度 | kurtosis(ax) |
| 时域 | 均方根 | RMS(ax) |
| 频域 | FFT低频能量 | sum(FFT[0:10]) |
| 频域 | FFT中频能量 | sum(FFT[10:30]) |
| 频域 | FFT高频能量 | sum(FFT[30:50]) |
| 角度 | 关节角度均值 | mean(elbow_angle) |
| 角度 | 关节角度范围 | max - min |

**特征向量** = 100维浮点数数组

#### 7.5.3 AI模型推理

```c
float features[100];
float output[6];

// 提取特征
extractFeatures(features, 100);

// AI推理
ei_classifier_run(features, 100, output, false);

// 输出结果
for (int i = 0; i < 6; i++) {
    printf("动作%d: %.2f%%\n", i, output[i] * 100);
}
```

**输出示例**：
```
动作0(前臂转动):   5%
动作1(手臂外展):   3%
动作2(肘关节弯曲): 85%  ← 识别结果
动作3(腕关节旋转): 2%
动作4(肩上举):     3%
动作5(步行平衡):   2%
```

#### 7.5.4 动作特征差异

| 动作 | 特征特点 |
|-----|---|
| 前臂转动 | 陀螺仪Y轴周期性变化，肘关节角度稳定 |
| 手臂外展 | 上臂Z轴大幅上升，肘关节角度变化 |
| 肘关节弯曲 | 肘关节角度周期性变化（40°-150°） |
| 腕关节旋转 | 手腕陀螺仪高频变化，肘关节稳定 |
| 肩上举 | 上臂Z轴持续上升，肘关节角度变化 |
| 步行平衡 | 上臂X轴周期性摇晃，步周期规律 |

#### 7.5.5 置信度判断

```c
int recognizeAction(float* output) {
    float max_prob = 0;
    int best_class = 0;

    for (int i = 0; i < 6; i++) {
        if (output[i] > max_prob) {
            max_prob = output[i];
            best_class = i;
        }
    }

    // 置信度阈值判断
    if (max_prob > 0.7) {
        return best_class;  // 识别成功
    } else {
        return -1;  // 无法识别（过渡动作）
    }
}
```

#### 7.5.6 完整识别流程图

```
     ┌─────────────────┐
     │  采集1秒数据窗口  │
     └────────┬────────┘
              ↓
     ┌─────────────────┐
     │  提取100维特征   │
     └────────┬────────┘
              ↓
     ┌─────────────────┐
     │  AI模型推理      │
     └────────┬────────┘
              ↓
     ┌─────────────────┐
     │ 输出6个动作概率  │
     └────────┬────────┘
              ↓
     ┌─────────────────┐
     │ 置信度 > 70%?   │
     └────────┬────────┘
         是   ↓   否
     ┌───────┴───────┐
     ↓               ↓
┌────────┐      ┌──────────┐
│返回动作ID│     │返回-1未知 │
└────┬────┘     └──────────┘
     ↓
┌──────────────┐
│ 更新当前动作   │
│ 计算评分      │
└──────────────┘
```

### 7. 运动质量评分

```c
typedef struct {
    float completion;   // 完成度 0-100
    float smoothness;   // 平稳度 0-100
    float frequency;    // 频率 0-100
    float total_score;  // 综合评分
} RehabScore_t;

// 评分计算
RehabScore_t calculateScore(int action, float* angles, int action_count) {
    RehabScore_t score;

    // 1. 完成度：实际角度 / 标准角度
    float standard_angle = getStandardAngle(action);
    float actual_angle = getMaxAngle(angles);
    score.completion = min(100, (actual_angle / standard_angle) * 100);

    // 2. 平稳度：基于角速度方差
    float gyro_variance = calculateVariance(gyro_buffer, 100);
    score.smoothness = max(0, (1 - gyro_variance / 50.0f) * 100);

    // 3. 频率：动作次数 / 标准次数
    score.frequency = min(100, (action_count / 20.0f) * 100);

    // 4. 综合评分
    score.total_score = score.completion * 0.6 +
                        score.smoothness * 0.3 +
                        score.frequency * 0.1;

    return score;
}

// 动作标准角度
float getStandardAngle(int action) {
    switch(action) {
        case ACTION_ELBOW_FLEX:    return 120.0f;  // 肘关节弯曲
        case ACTION_ARM_ABDUCTION: return 90.0f;   // 手臂外展
        case ACTION_SHOULDER_LIFT: return 150.0f;  // 肩上举
        case ACTION_WRIST_ROT:     return 90.0f;   // 腕关节旋转
        default:                   return 100.0f;
    }
}
```

### 8. 智能反馈

```c
void provideFeedback(RehabScore_t score) {
    if (score.total_score < 60) {
        setVibration(200, 3);  // 振动提醒
        sendToApp("角度不足，请继续加大");
    } else if (score.total_score > 80) {
        sendToApp("做得很好！");
    }
}
```

### 9. TFTLCD触摸交互界面（LVGL）

使用正点原子3.5寸TFTLCD + LVGL图形库，支持动画效果：

```c
#include "lvgl.h"
#include "lv_port_disp.h"
#include "lv_port_indev.h"

// 界面结构
typedef enum {
    SCREEN_HOME,       // 主界面
    SCREEN_TRAINING,   // 训练界面
    SCREEN_HISTORY,    // 历史记录
    SCREEN_SETTINGS    // 设置界面
} ScreenType_t;

// LVGL初始化
void lvgl_init(void) {
    lv_init();
    lv_port_disp_init();   // 显示驱动
    lv_port_indev_init();  // 触摸驱动
}

// 主界面
void create_home_screen(void) {
    lv_obj_t *scr = lv_obj_create(NULL, NULL);

    // 标题动画
    lv_obj_t *title = lv_label_create(scr, NULL);
    lv_label_set_text(title, "AI-RehabBand");
    lv_obj_set_x(title, 80);
    lv_obj_set_y(title, 60);
    lv_label_set_style(title, LV_LABEL_STYLE_MAIN, &lv_style_pretty);

    // 副标题
    lv_obj_t *subtitle = lv_label_create(scr, NULL);
    lv_label_set_text(subtitle, "智能康复臂带");
    lv_obj_set_x(subtitle, 100);
    lv_obj_set_y(subtitle, 100);

    // 动画：标题淡入
    lv_anim_t a;
    lv_anim_init(&a);
    lv_anim_set_var(&a, title);
    lv_anim_set_exec_cb(&a, (lv_anim_exec_xcb_t)lv_obj_set_x);
    lv_anim_set_values(&a, -200, 80);
    lv_anim_set_time(&a, 500);
    lv_anim_start(&a);

    // 按钮：开始训练
    lv_obj_t *btn_train = lv_btn_create(scr, NULL);
    lv_obj_set_size(btn_train, 160, 50);
    lv_obj_set_x(btn_train, 80);
    lv_obj_set_y(btn_train, 200);
    lv_obj_set_event_cb(btn_train, event_handler_train);

    lv_obj_t *label_train = lv_label_create(btn_train, NULL);
    lv_label_set_text(label_train, "开始训练");

    // 按钮：历史记录
    lv_obj_t *btn_history = lv_btn_create(scr, NULL);
    lv_obj_set_size(btn_history, 160, 50);
    lv_obj_set_x(btn_history, 80);
    lv_obj_set_y(btn_history, 280);
    lv_obj_set_event_cb(btn_history, event_handler_history);

    lv_obj_t *label_history = lv_label_create(btn_history, NULL);
    lv_label_set_text(label_history, "历史记录");

    // 按钮：系统设置
    lv_obj_t *btn_settings = lv_btn_create(scr, NULL);
    lv_obj_set_size(btn_settings, 160, 50);
    lv_obj_set_x(btn_settings, 80);
    lv_obj_set_y(btn_settings, 360);
    lv_obj_set_event_cb(btn_settings, event_handler_settings);

    lv_obj_t *label_settings = lv_label_create(btn_settings, NULL);
    lv_label_set_text(label_settings, "系统设置");

    lv_scr_load(scr);
}

// 训练界面
void create_training_screen(void) {
    lv_obj_t *scr = lv_obj_create(NULL, NULL);

    // 当前动作标签
    lv_obj_t *action_label = lv_label_create(scr, NULL);
    lv_label_set_text(action_label, "肘关节弯曲");
    lv_obj_set_x(action_label, 100);
    lv_obj_set_y(action_label, 30);
    lv_obj_set_style(action_label, &lv_style_pretty);

    // 角度显示 - 大字体动画
    lv_obj_t *angle_label = lv_label_create(scr, NULL);
    lv_label_set_text(angle_label, "120");
    lv_obj_set_x(angle_label, 100);
    lv_obj_set_y(angle_label, 100);
    lv_label_set_style(angle_label, &lv_style_pretty);

    // 角度单位
    lv_obj_t *unit_label = lv_label_create(scr, NULL);
    lv_label_set_text(unit_label, "度");
    lv_obj_set_x(unit_label, 200);
    lv_obj_set_y(unit_label, 110);

    // 评分进度条（带动画）
    lv_obj_t *bar = lv_bar_create(scr, NULL);
    lv_obj_set_size(bar, 260, 30);
    lv_obj_set_x(bar, 30);
    lv_obj_set_y(bar, 250);
    lv_bar_set_value(bar, 85, LV_ANIM_ON);

    // 评分数值
    lv_obj_t *score_label = lv_label_create(scr, NULL);
    lv_label_set_text_fmt(score_label, "评分: %d", 85);
    lv_obj_set_x(score_label, 100);
    lv_obj_set_y(score_label, 300);

    // 返回按钮
    lv_obj_t *btn_back = lv_btn_create(scr, NULL);
    lv_obj_set_size(btn_back, 80, 40);
    lv_obj_set_x(btn_back, 200);
    lv_obj_set_y(btn_back, 380);
    lv_obj_set_event_cb(btn_back, event_handler_back);

    lv_obj_t *label_back = lv_label_create(btn_back, NULL);
    lv_label_set_text(label_back, "返回");

    lv_scr_load(scr);
}

// 角度变化动画
void animate_angle_change(int new_angle) {
    static int old_angle = 0;
    if (old_angle != new_angle) {
        lv_anim_t a;
        lv_anim_init(&a);
        lv_anim_set_var(&a, angle_label);
        lv_anim_set_exec_cb(&a, (lv_anim_exec_xcb_t)lv_label_set_text_fmt);
        lv_anim_set_values(&a, old_angle, new_angle);
        lv_anim_set_time(&a, 200);
        lv_anim_start(&a);
        old_angle = new_angle;
    }
}

// 评分进度条动画
void animate_score_change(int new_score) {
    lv_anim_t a;
    lv_anim_init(&a);
    lv_anim_set_var(&a, bar);
    lv_anim_set_exec_cb(&a, (lv_anim_exec_xcb_t)lv_bar_set_value);
    lv_anim_set_values(&a, lv_bar_get_value(bar), new_score);
    lv_anim_set_time(&a, 300);
    lv_anim_start(&a);
}

// 事件处理
void event_handler_train(lv_obj_t *btn, lv_event_t event) {
    if (event == LV_EVENT_CLICKED) {
        create_training_screen();
    }
}

void event_handler_back(lv_obj_t *btn, lv_event_t event) {
    if (event == LV_EVENT_CLICKED) {
        create_home_screen();
    }
}

// LVGL主任务（5ms调用一次）
void lvgl_task(void) {
    lv_task_handler();
}
```

**LVGL界面功能**：
| 界面 | 功能 | 动画效果 |
|-----|---|---|
| 主界面 | 标题淡入、按钮点击 | 标题从左侧滑入 |
| 训练界面 | 角度显示、进度条 | 角度数字平滑变化、进度条渐变 |
| 历史记录 | 曲线图表 | 曲线绘制动画 |
| 设置界面 | 参数调节 | 滑块拖动动画 |

**LVGL优势**：
- 丰富的动画效果
- 专业的UI外观
- 触摸手势支持
- 内存占用可控（<100KB）

### 10. 触摸驱动（GT911电容触摸）

```c
#include "gt911.h"
#include "i2c.h"

// 触摸坐标结构
typedef struct {
    uint16_t x;
    uint16_t y;
    uint8_t  state;  // 0=释放, 1=按下
} TouchPoint_t;

// GT911初始化
int8_t gt911_init(void) {
    uint8_t cfg[184] = {0};
    // 读取配置
    if (GT911_ReadReg(0x8047, cfg, 184) != 0) {
        return -1;  // 初始化失败
    }
    return 0;
}

// 读取触摸点
uint8_t gt911_get_points(TouchPoint_t *points, uint8_t max_points) {
    uint8_t buffer[40] = {0};
    uint8_t num = 0;

    // 读取触摸状态
    GT911_ReadReg(0x814E, buffer, 1);
    num = buffer[0] & 0x0F;

    if (num > 0 && num <= max_points) {
        // 读取触摸点坐标
        GT911_ReadReg(0x8150, buffer, num * 8);

        for (uint8_t i = 0; i < num; i++) {
            points[i].x = (buffer[i*8 + 1] << 8) | buffer[i*8];
            points[i].y = (buffer[i*8 + 3] << 8) | buffer[i*8 + 2];
            points[i].state = 1;
        }

        // 清除触摸标志
        buffer[0] = 0;
        GT911_WriteReg(0x814E, buffer, 1);
    }

    return num;
}

// LVGL触摸输入设备初始化
void lv_port_indev_init(void) {
    static lv_indev_data_t indev_data;

    // 配置触摸输入设备
    indev_data.type = LV_INDEV_TYPE_POINTER;
    indev_data.read_cb = touch_read_cb;

    lv_indev_add(&indev_data);
}

// LVGL触摸读取回调
bool touch_read_cb(lv_indev_data_t *data) {
    static TouchPoint_t last_point = {0, 0, 0};
    TouchPoint_t point;

    uint8_t num = gt911_get_points(&point, 1);

    if (num > 0) {
        data->point.x = point.x;
        data->point.y = point.y;
        data->state = LV_INDEV_STATE_PR;
        last_point = point;
    } else {
        data->point.x = last_point.x;
        data->point.y = last_point.y;
        data->state = LV_INDEV_STATE_REL;
    }

    return false;
}

// 触摸校准（可选）
void touch_calibrate(void) {
    // 4点校准
    uint16_t cal_points[4][2] = {
        {20, 20},        // 左上
        {300, 20},       // 右上
        {20, 460},       // 左下
        {300, 460}       // 右下
    };

    // 依次提示用户点击4个点
    for (int i = 0; i < 4; i++) {
        // 显示校准点
        draw_cal_point(cal_points[i][0], cal_points[i][1]);

        // 等待用户点击
        TouchPoint_t point;
        while (gt911_get_points(&point, 1) == 0);

        // 保存校准数据
        cal_data[i][0] = point.x;
        cal_data[i][1] = point.y;
    }

    // 计算校准参数
    calculate_cal_params();
}
```

**触摸参数**：
| 参数 | 值 |
|-----|-----|
| 触摸芯片 | GT911 |
| 接口 | I2C |
| 触摸点数 | 5点同时触摸 |
| 采样率 | 100Hz |
| 精度 | ±1mm |

### 10. 蓝牙数据通信

```c
// 数据包格式（10Hz发送）
typedef struct {
    uint8_t header;        // 0xAA
    uint8_t action;        // 当前动作
    float elbow_angle;     // 肘关节角度
    float score;           // 综合评分
    uint8_t checksum;
} DataPacket_t;

void sendDataToApp(float elbow_angle, int action, float score) {
    DataPacket_t pkt = {
        .header = 0xAA,
        .action = action,
        .elbow_angle = elbow_angle,
        .score = score,
        .checksum = calcChecksum(&pkt, sizeof(pkt)-1)
    };
    BLE_Send((uint8_t*)&pkt, sizeof(pkt));
}
```

### 10. 关节角度测量范围

| 关节 | 测量范围 | 正常范围 | 合格标准 |
|---|---|---|---|
| 肘关节 | 0°-180° | 0°-150° | ≥120° |
| 肩关节 | 0°-180° | 0°-170° | ≥90° |
| 前臂旋转 | 0°-360° | 0°-180° | ≥90° |
| 腕关节 | -90°-90° | -90°-90° | ≥45° |

---

## 📅 分阶段实施计划

### 第1阶段：硬件采购与原型验证（第1-2周）

#### 采购清单

| 物品 | 型号 | 价格 | 用途 |
|---|---|---|---|
| MCU开发板×2 | NUCLEO-U575ZI-Q | ¥700 | 上臂端+手腕端双主控 |
| 6轴传感器×2 | LSM6DSV16X模块 | ¥400 | 上臂+手腕姿态 |
| 气压传感器 | LPS22DF | ¥150 | 方案B增强 |
| TFTLCD屏幕 | 正点原子3.5寸触摸屏 | ¥180 | 本地显示+触摸交互 |
| 蓝牙模块 | HM-10/BLE | ¥80 | App通信 |
| 锂电池+充电 | 250mAh+TP4056 | ¥100 | 电源 |
| 魔术贴绑带+表带 | - | ¥60 | 固定传感器 |
| PCB+焊接 | - | ¥400 | 方案B |
| 其他 | - | ¥150 | - |

#### 任务分配

**硬件工程师（40h）**：
- 接收所有硬件物料
- 测试NUCLEO开发板基础功能（LED+按键）
- 验证LSM6DSV16X传感器通讯（I2C连接）
- 搭建原型连接（2个6轴传感器+OLED+蓝牙）
- 制作原理图文档

**固件工程师（30h）**：
- 搭建STM32CubeIDE开发环境
- 创建FreeRTOS项目框架
- 验证UART/I2C/SPI基础通讯
- 编写LSM6DSV16X驱动代码

**App开发（20h）**：
- Flutter项目初始化
- BLE通讯库集成

#### 验证标准

✓ NUCLEO板LED能闪烁
✓ 串口能打印"Hello World"
✓ I2C检测到0x6A/0x6B地址
✓ 能读取两个传感器的加速度值
✓ 值在合理范围内（静止时≈0，运动时>1G）

### 第2阶段：固件开发与AI模型训练（第3-6周）

| 周 | 任务 | 输出 |
|----|---|---|
| 3-4 | 传感器驱动+AHRS算法 | 姿态融合正常 |
| 3-4 | FreeRTOS任务框架 | 多任务运行 |
| 5-6 | AI模型训练 | Edge Impulse模型 |
| 5-6 | 评分算法集成 | 评分计算正确 |

**功耗优化**：
```c
typedef enum {
    MODE_SLEEP,     // 1 µA
    MODE_STANDBY,   // 10 µA
    MODE_NORMAL,    // 100 mA
    MODE_ACTIVE     // 150 mA
} PowerMode_t;

// 续航估算：250mAh电池，优化后约5天
```

### 第3阶段：App开发与系统联调（第5-6周）

#### 任务分配

**硬件工程师（50h）**：
- 电源管理电路设计
- PCB原理图绘制
- 气压传感器集成
- PCB设计

**固件工程师（90h）**：
- FreeRTOS框架+AI集成
- 功耗优化+测试
- 评分算法实现

**App开发（70h）**：
- Flutter项目+BLE基础
- 3个屏幕UI+本地存储
- 进度趋势展示

#### 里程碑验证标准

| 里程碑 | 验证项 | 标准 |
|---|---|---|
| 硬件原型（第2周） | LED闪烁、I2C通讯、蓝牙连接 | ✓全部通过 |
| AI模型（第4周末） | Edge Impulse精度>90%，推理时间<100ms | ✓ |
| App联动（第5周末） | 蓝牙连接、数据接收、UI刷新 | ✓全部通过 |
| 完整系统（第6周末） | 启动<30秒、续航≥3天、识别准确率>85% | ✓ |

---

## 🏆 核心创新点

1. **双传感器关节角度计算** - 通过上臂+手腕相对姿态精确获取肘关节角度（0°-180°）

2. **康复进度量化** - 完成度×60% + 平稳度×30% + 频率×10%

3. **智能反馈** - 评分<60%振动提醒，>80%语音鼓励

4. **本地AI推理** - STM32CubeAI部署轻量CNN（<50KB），隐私安全

---

## 🎨 智能穿戴设计

### 1. 外观结构设计

**整体佩戴方式**：
```
┌─────────────────────────────────────────────────────────┐
│                    智能康复臂带                           │
│                                                         │
│    ┌─────────────┐         ┌─────────────┐              │
│    │  上臂传感器  │ ────→  │   主控模块   │ ───→ 手腕      │
│    │   (臂带)    │  魔术贴 │  (NUCLEO)   │   传感器       │
│    └─────────────┘         └─────────────┘              │
│                                                         │
│    佩戴效果：                                            │
│    ┌─────────────────────────────────────┐              │
│    │    上臂    │    前臂    │    手腕    │              │
│    │   [====]  │            │   [手表]   │              │
│    │   传感器   │            │   传感器    │             │
│    └─────────────────────────────────────┘              │
└─────────────────────────────────────────────────────────┘
```

**尺寸规格**：
| 部件 | 尺寸 | 重量 | 材质 |
|-----|---|-----|---|
| 上臂臂带 | 50×8×1cm | 25g | 弹性尼龙+魔术贴 |
| 主控模块 | 40×30×10mm | 20g | 3D打印外壳 |
| 手腕传感器 | 35×30×8mm | 15g | 硅胶表带 |
| **总计** | - | **~60g** | - |

**外观渲染描述**：
- 上臂臂带：深蓝色弹性材质，银色传感器模块
- 主控模块：白色ABS塑料外壳，Type-C充电口
- 手腕传感器：黑色硅胶表带，隐藏式传感器

### 2. 佩戴方式说明

**上臂传感器佩戴**：
1. 将臂带套入上臂中段（肘关节上10cm）
2. 调整魔术贴松紧度（可插入1根手指为宜）
3. 传感器模块朝向身体外侧
4. 确保传感器与皮肤贴合无晃动

**手腕传感器佩戴**：
1. 将表带绕手腕一圈
2. 传感器位于手背上方
3. 表带扣紧至舒适位置

**佩戴效果**：
- 日常佩戴无异物感
- 运动时传感器不滑动
- 洗澡时可拆卸
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

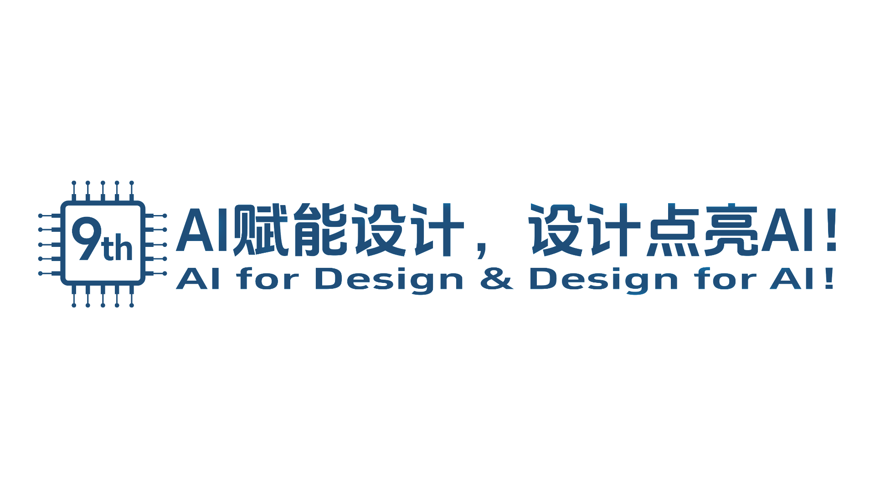
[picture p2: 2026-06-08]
视频需求.png

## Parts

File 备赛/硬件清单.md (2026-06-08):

# 硬件清单

## 一、硬件总体思路

当前硬件设计遵循单主控、双 IMU、简化肌电采集的思路，以保证系统结构清晰、开发难度可控，并能够在一个月左右完成集成与演示。

## 二、核心硬件清单

| 模块 | 推荐型号 | 数量 | 主要作用 | 备注 |
|---|---|---|---|---|
| 主控开发板 | STM32U575 开发板 | 1 | 数据处理、算法运行、任务调度 | 项目核心控制单元 |
| 上臂 IMU | 逐飞 IMU660RB（核心芯片 LSM6DSRTR） | 1 | 上臂姿态采集 | 固定在上臂位置 |
| 手腕 IMU | 逐飞 IMU660RB（核心芯片 LSM6DSRTR） | 1 | 手腕姿态采集 | 固定在手腕位置 |
| 肌电采集模块 | MyoWare 2.0 / ADS1292R 简化板 | 1 组 | 采集主动参与信号 | 建议先用成熟模块 |
| 电极贴片 | 一次性肌电电极片 | 若干 | 肌电信号采集 | 需考虑更换成本 |
| OLED 屏幕 | 0.96 寸 I2C OLED | 1 | 本地显示训练状态 | 显示关键参数 |
| 蓝牙模块 | HM-10 / ESP32-C3 | 1 | 手机通信 | 串口透传优先 |
| 电池 | 500mAh 锂电池 | 1 | 便携供电 | MVP 阶段以续航稳定为主 |
| 充电管理 | TP4056 或集成充电板 | 1 | 电池充电与保护 | 便于原型调试 |
| 固定结构 | 臂带、表带、3D 打印外壳 | 1 套 | 佩戴与封装 | 以稳定固定为第一优先级 |

## 三、各模块详细说明

### 1. 主控

STM32U575 作为主控，负责：

- 采集 IMU 与肌电数据。
- 运行滤波、姿态解算和规则识别逻辑。
- 计算评分与异常提示。
- 驱动 OLED 显示。
- 与手机端进行蓝牙通信。

选择单主控而非双主控的原因是可以减少无线同步、双端调试和系统联调难度。

### 2. IMU 传感器

双 IMU 是本项目的核心感知模块：

- 上臂 IMU 用于反映大臂姿态变化。
- 手腕 IMU 用于反映前臂和手部姿态变化。
- 通过上下两点的相对姿态关系估算肘关节角度。

当前版本优先采用逐飞 `IMU660RB` 模块，其核心芯片为 `LSM6DSRTR`。这样做的原因是：

- 现成模块便于快速接线和固定，适合 MVP 周期。
- 逐飞模块资料和例程较多，便于缩短驱动调试时间。
- 6 轴能力已经能够满足当前的相对姿态估计、动作识别和角度变化分析需求。

MVP 阶段对 IMU 的要求以稳定采样和姿态变化趋势正确为主，不强求复杂九轴融合。

### 3. 肌电采集模块

肌电部分建议优先使用现成模块，而不是自制高精度模拟前端。原因如下：

- 一个自然月内自制肌电前端风险较高。
- 现成模块更适合先做主动参与阈值判定。
- 比赛阶段更重视系统闭环，而非医学级信号精度。

推荐实现目标：

- 能稳定采集到发力前后幅值变化。
- 能通过整流和平滑得到可用参与度指标。
- 能在界面上显示“有无主动参与”或“参与强弱”。

### 4. 显示模块

OLED 只负责展示必要信息：

- 当前模式
- 当前动作
- 角度值
- EMG 状态
- 次数
- 评分

MVP 阶段不建议上大尺寸触摸屏，以免额外增加 UI 和驱动工作量。

### 5. 蓝牙模块

蓝牙模块主要用于训练结果同步，不要求做高频实时波形传输。推荐优先同步摘要数据，例如：

- 动作类别
- 最大角度
- 完成次数
- 主动参与次数
- 最终评分

### 6. 供电与封装

供电与封装在比赛作品中直接影响观感和稳定性。建议：

- 使用独立锂电池供电，避免全程 USB 拖线。
- 外壳优先保证固定牢靠和佩戴稳定。
- 电极贴片与传感器走线应尽量整齐，避免演示时脱落。

## 四、建议硬件连接关系

```text
上臂 IMU --- I2C/SPI ---|
                         |
手腕 IMU --- I2C/SPI ----|--> STM32U575 --> OLED
                         |               \
肌电模块 ---- ADC/UART --|                --> 蓝牙模块
```

## 五、MVP 阶段采购优先级

### 必须优先采购

- STM32U575 开发板
- 2 个 IMU 模块
- 肌电采集模块与电极贴片
- OLED
- 蓝牙模块

### 可后补采购

- 电池与充电板
- 外壳材料
- 备用电极与绑带

## 六、硬件实施建议

1. 先在桌面环境打通主控、IMU、肌电、OLED、蓝牙。
2. 再进入穿戴结构固定阶段。
3. 先保证采集稳定，再优化外观和封装。
4. 肌电模块优先做“能用”，不要一开始追求高精度医学指标。

## 七、当前推荐佩戴定版

MVP 当前建议采用如下定版结构：

- 患侧上臂外侧主控盒，集成主控、OLED、蓝牙、电池、上臂 IMU 和肌电模块。
- 患侧前臂远端背侧固定一个轻量 IMU 模块。
- 患侧肱二头肌布置单路肌电电极。

具体的人体佩戴位置、模块方向和固定方式见 `人体佩戴与模块朝向规范.md`。

各模块之间的连接关系、推荐接口分配和布线顺序见 `系统硬件连接图说明.md`。

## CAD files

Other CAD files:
lcd/P183B001-CTP/P183B001-CTP 总成 20241109.dwg

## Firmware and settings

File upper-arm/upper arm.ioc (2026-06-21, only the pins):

Mcu.UserName=STM32U575RITx
PA0.GPIO_Label=DEBUG_TX
PA0.Signal=UART4_TX
PA1.GPIO_Label=DEBUG_RX
PA1.Signal=UART4_RX
PA10.GPIO_Label=WIRELESS_RXD
PA10.Signal=USART1_RX
PA11.GPIO_Label=VIBRATION_MOTOR
PA11.Signal=GPIO_Output
PA12.GPIO_Label=USER_KEY
PA12.Signal=GPIO_Input
PA2.GPIO_Label=DATA_TXD
PA2.Signal=USART2_TX
PA3.GPIO_Label=DATA_RXD
PA3.Signal=USART2_RX
PA4.GPIO_Label=IMU_ARM_CS
PA4.Signal=GPIO_Output
PA5.GPIO_Label=IMU_ARM_SCK
PA5.Signal=SPI1_SCK
PA6.GPIO_Label=IMU_ARM_MISO
PA6.Signal=SPI1_MISO
PA7.GPIO_Label=IMU_ARM_MOSI
PA7.Signal=SPI1_MOSI
PA8.GPIO_Label=LCD_BL
PA8.Signal=GPIO_Output
PA9.GPIO_Label=WIRELESS_TXD
PA9.Signal=USART1_TX
PB0.GPIO_Label=EMG_ADC
PB0.Signal=ADC1_IN15
PB10.Signal=I2C2_SCL
PB14.Signal=I2C2_SDA
PB2.GPIO_Label=BUZZER
PB2.Signal=GPIO_Output
PB6.GPIO_Label=TP_SCL
PB6.Signal=I2C1_SCL
PB7.GPIO_Label=TP_SDA
PB7.Signal=I2C1_SDA
PB8.GPIO_Label=LCD_DC
PB8.Signal=GPIO_Output
PB9.GPIO_Label=LCD_RST
PB9.Signal=GPIO_Output
PC0.GPIO_Label=MODE_KEY
PC0.Signal=GPIO_Input
PC10.GPIO_Label=LCD_SCL
PC10.Signal=SPI3_SCK
PC11.GPIO_Label=LCD_SDO
PC11.Signal=SPI3_MISO
PC12.GPIO_Label=LCD_SDA
PC12.Signal=SPI3_MOSI
PC13.GPIO_Label=RUN_LED
PC13.Signal=GPIO_Output
PC4.GPIO_Label=TP_INT
PC4.Signal=GPIO_Input
PC5.GPIO_Label=TP_RST
PC5.Signal=GPIO_Output
PC6.GPIO_Label=LED_STATUS
PC6.Signal=GPIO_Output

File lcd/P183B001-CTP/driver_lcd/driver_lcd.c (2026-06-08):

#include "driver_lcd.h"
#include "gpio.h"
#include "spi.h"
#include "cmsis_os.h"
#include "lcdfont.h"

#define LCD_BUFFER_SIZE 7200

// 定义一个全局的 LCD 数据缓冲区
uint8_t  lcd_buffer[LCD_BUFFER_SIZE];

extern SPI_HandleTypeDef hspi3;         //  SPI2  句柄
extern DMA_HandleTypeDef hdma_spi3_tx;  // DMA SPI2 TX 句柄

/******************************************************************************
      函数说明：LCD串行数据写入函数
      入口数据：dat  要写入的串行数据
      返回值：  无
******************************************************************************/
void LCD_Writ_Bus_DMA_Interrupt(uint8_t *dat, size_t length)
{
  // 选择 LCD 设备 (拉低 CS 引脚)
  LCD_CS_Clr();  

  // 使用 DMA 启动 SPI 传输
	HAL_SPI_Transmit_DMA(&hspi3, dat, length);
	
	while (hspi3.State != HAL_SPI_STATE_READY) {
        // 添加超时处理防止死循环
    }
	
	// 选择 LCD 设备 (拉高 CS 引脚)
  LCD_CS_Set(); 
}




/******************************************************************************
      函数说明：LCD写入数据
      入口数据：dat 写入的数据
      返回值：  无
******************************************************************************/
void LCD_WR_DATA8(uint8_t dat)
{
    // 将单个字节的地址传递给 LCD_Writ_Bus_DMA_Interrupt
    LCD_Writ_Bus_DMA_Interrupt(&dat, 1);  // 传递指针和长度（1字节）
}


/******************************************************************************
      函数说明：LCD写入数据
      入口数据：dat 写入的数据
      返回值：  无
******************************************************************************/
void LCD_WR_DATA(uint16_t dat)
{
    // 强制将 16 位数据作为字节流传递
    uint8_t buffer[2];
    buffer[0] = (uint8_t)(dat >> 8);  // 高字节
    buffer[1] = (uint8_t)(dat & 0xFF); // 低字节

    // 通过 DMA 传输 2 字节
    LCD_Writ_Bus_DMA_Interrupt(buffer, 2);
}


/******************************************************************************
      函数说明：LCD写入命令
      入口数据：dat 写入的命令
      返回值：  无
******************************************************************************/
void LCD_WR_REG(uint8_t dat)
{
	LCD_DC_Clr();//写命令
	LCD_Writ_Bus_DMA_Interrupt(&dat, 1);
	LCD_DC_Set();//写数据
}


/******************************************************************************
      函数说明：设置起始和结束地址
      入口数据：x1,x2 设置列的起始和结束地址
                y1,y2 设置行的起始和结束地址
      返回值：  无
******************************************************************************/
void LCD_Address_Set(uint16_t x1,uint16_t y1,uint16_t x2,uint16_t y2)
{
	if(USE_HORIZONTAL==0)
	{
		LCD_WR_REG(0x2a);//列地址设置
		LCD_WR_DATA(x1);
		LCD_WR_DATA(x2);
		LCD_WR_REG(0x2b);//行地址设置
		LCD_WR_DATA(y1);
		LCD_WR_DATA(y2);
		LCD_WR_REG(0x2c);//储存器写
	}
	else if(USE_HORIZONTAL==2)
	{
		LCD_WR_REG(0x2a);//列地址设置
		LCD_WR_DATA(x1);
		LCD_WR_DATA(x2);
		LCD_WR_REG(0x2b);//行地址设置
		LCD_WR_DATA(y1);
		LCD_WR_DATA(y2);
		LCD_WR_REG(0x2c);//储存器写
	}
	else
	{
		LCD_WR_REG(0x2a);//列地址设置
		LCD_WR_DATA(x1);
		LCD_WR_DATA(x2);
		LCD_WR_REG(0x2b);//行地址设置
		LCD_WR_DATA(y1);
		LCD_WR_DATA(y2);
		LCD_WR_REG(0x2c);//储存器写
	}
}

/******************************************************************************
      函数说明：初始化LCD（这个函数要连续运行两遍，神奇的BUG。）
      入口数据：无
      返回值：  无
******************************************************************************/

void LCD_Init(void)
{

	
	LCD_RES_Clr();//复位
	HAL_Delay(100);
	LCD_RES_Set();
	HAL_Delay(100);
	
	LCD_BLK_Set();//打开背光
	HAL_Delay(100);
	
	//************* Start Initial Sequence **********//
	LCD_WR_REG(0x11); //Sleep out 
	HAL_Delay(120);   //延时 120ms 
	//************* Start Initial Sequence **********//
	LCD_WR_REG(0x36);
	if(USE_HORIZONTAL==0)LCD_WR_DATA8(0x00);
	else if(USE_HORIZONTAL==1)LCD_WR_DATA8(0xC0);
	else if(USE_HORIZONTAL==2)LCD_WR_DATA8(0x70);
	else LCD_WR_DATA8(0xA0);

	LCD_WR_REG(0x3A);			
	LCD_WR_DATA8(0x05);

	LCD_WR_REG(0xB2);			
	LCD_WR_DATA8(0x0C);
	LCD_WR_DATA8(0x0C); 
	LCD_WR_DATA8(0x00); 
	LCD_WR_DATA8(0x33); 
	LCD_WR_DATA8(0x33); 			

	LCD_WR_REG(0xB7);			
	LCD_WR_DATA8(0x35);

	LCD_WR_REG(0xBB);			
	LCD_WR_DATA8(0x32); //Vcom=1.35V
					
	LCD_WR_REG(0xC2);
	LCD_WR_DATA8(0x01);

	LCD_WR_REG(0xC3);			
	LCD_WR_DATA8(0x15); //GVDD=4.8V  颜色深度
				
	LCD_WR_REG(0xC4);			
	LCD_WR_DATA8(0x20); //VDV, 0x20:0v

	LCD_WR_REG(0xC6);			
	LCD_WR_DATA8(0x0F); //0x0F:60Hz        	

	LCD_WR_REG(0xD0);			
	LCD_WR_DATA8(0xA4);
	LCD_WR_DATA8(0xA1); 

	LCD_WR_REG(0xE0);
	LCD_WR_DATA8(0xD0);   
	LCD_WR_DATA8(0x08);   
	LCD_WR_DATA8(0x0E);   
	LCD_WR_DATA8(0x09);   
	LCD_WR_DATA8(0x09);   
	LCD_WR_DATA8(0x05);   
	LCD_WR_DATA8(0x31);   
	LCD_WR_DATA8(0x33);   
	LCD_WR_DATA8(0x48);   
	LCD_WR_DATA8(0x17);   
	LCD_WR_DATA8(0x14);   
	LCD_WR_DATA8(0x15);   
	LCD_WR_DATA8(0x31);   
	LCD_WR_DATA8(0x34);   

	LCD_WR_REG(0xE1);     
	LCD_WR_DATA8(0xD0);   
	LCD_WR_DATA8(0x08);   
	LCD_WR_DATA8(0x0E);   
	LCD_WR_DATA8(0x09);   
	LCD_WR_DATA8(0x09);   
	LCD_WR_DATA8(0x15);   
	LCD_WR_DATA8(0x31);   
	LCD_WR_DATA8(0x33);   
	LCD_WR_DATA8(0x48);   
	LCD_WR_DATA8(0x17);   
	LCD_WR_DATA8(0x14);   
	LCD_WR_DATA8(0x15);   
	LCD_WR_DATA8(0x31);   
	LCD_WR_DATA8(0x34);
	LCD_WR_REG(0x21); 

	LCD_WR_REG(0x29);
}

/******************************************************************************
      函数说明：在指定区域填充颜色
      入口数据：xsta,ysta   起始坐标
                xend,yend   终止坐标
								color       要填充的颜色
      返回值：  无
******************************************************************************/

void LCD_Fill(uint16_t xsta,uint16_t ysta,uint16_t xend,uint16_t yend,uint16_t color)
{          
	uint16_t i,j; 
	LCD_Address_Set(xsta,ysta,xend-1,yend-1);//设置显示范围
	for(i=ysta;i<yend;i++)
	{													   	 	
		for(j=xsta;j<xend;j++)
		{
			LCD_WR_DATA(color);
		}
	} 					  	    
}
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

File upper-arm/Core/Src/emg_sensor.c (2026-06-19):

/* ==================== Include ==================== */
#include "emg_sensor.h"

#include "adc.h"
#include "app_freertos.h"
#include "rehab_utils.h"
#include "tim.h"
#include <math.h>
#include <stdio.h>
#include <string.h>
/* ==================== 宏定义 ==================== */
#define EMG_SENSOR_ADC_MAX             (4095.0f)
#define EMG_SENSOR_VREF_MV             (3300.0f)
/* 500Hz 下采集 2 秒静息数据，用于建立个体化基线和噪声水平。 */
#define EMG_SENSOR_BASELINE_SAMPLES    (EMG_SENSOR_SAMPLE_RATE_HZ * 2U)
#define EMG_SENSOR_WARMUP_SAMPLES      (EMG_SENSOR_SAMPLE_RATE_HZ * 3U)
#define EMG_SENSOR_ENVELOPE_ALPHA      (0.15f)
/* 64 点约等于 128ms 窗口，用于估计肌电短时 RMS。 */
#define EMG_SENSOR_RMS_WINDOW_LEN      (64U)
/* 噪声阈值倍数，避免静息抖动被误判为主动发力。 */
#define EMG_SENSOR_NOISE_MULTIPLIER    (4.0f)
#define EMG_SENSOR_BASE_DEBUG          (0U)

/* ==================== 全局静态变量 ==================== */
/* ADC DMA 环形缓冲区，半满/满中断分别处理前后 32 点。 */
static uint16_t emg_adc_buffer[EMG_SENSOR_BUFFER_LEN];
/* RMS 不直接保存原始 ADC，而是保存去基线后的幅值平方滑动均值。 */
static float emg_rms_window[EMG_SENSOR_RMS_WINDOW_LEN];
static EmgSensor_State_t emg_state;
/* baseline_square_sum 用 E[x^2] - E[x]^2 估计静息噪声方差。 */
static uint32_t emg_baseline_sum;
static uint64_t emg_baseline_square_sum;
static uint32_t emg_baseline_count;
static uint32_t emg_warmup_count;
static float emg_active_delta = EMG_SENSOR_DEFAULT_ACTIVE_DELTA;
static float emg_full_scale_delta = EMG_SENSOR_DEFAULT_FULL_SCALE_DELTA;
static Rehab_FirstOrderFilter_t emg_envelope_filter;
static Rehab_MovingAverage_t emg_rms_average;

/**
 * @brief 完成静息标定，计算 baseline、noise_level 并初始化后续滤波器。
 *
 * baseline 用于去除传感器直流偏置；noise_level 用于估计静息噪声强度。
 * 若噪声推导出的阈值高于默认阈值，则自动抬高激活阈值，减少误触发。
 */
static void EmgSensor_FinishBaseline(void)
{
  float mean;
  float mean_square;
  float variance;
  float threshold_from_noise;

  if (emg_baseline_count == 0U)
  {
    return;
  }

  mean = (float)emg_baseline_sum / (float)emg_baseline_count;
  mean_square = (float)emg_baseline_square_sum / (float)emg_baseline_count;
  variance = mean_square - (mean * mean);
  /* 浮点舍入可能让理论上非负的方差变成极小负数。 */
  if (variance < 0.0f)
  {
    variance = 0.0f;
  }

  emg_state.baseline = mean;
  emg_state.noise_level = sqrtf(variance);
  emg_state.rectified = 0.0f;
  emg_state.envelope = 0.0f;
  emg_state.rms = 0.0f;
  emg_state.active = 0U;
  emg_state.strength = 0U;
  emg_state.participation = 0U;
  emg_state.calibrated = 1U;

  if (EMG_SENSOR_BASE_DEBUG != 0U)
  {
    printf("EMG_BASE_DBG count=%lu sum=%lu mean_x10=%ld noise_x10=%ld state_size=%u\r\n",
           (unsigned long)emg_baseline_count,
           (unsigned long)emg_baseline_sum,
           (long)(mean * 10.0f),
           (long)(emg_state.noise_level * 10.0f),
           (unsigned int)sizeof(EmgSensor_State_t));
  }

  threshold_from_noise = emg_state.noise_level * EMG_SENSOR_NOISE_MULTIPLIER;
  if (threshold_from_noise > emg_active_delta)
  {
    emg_active_delta = threshold_from_noise;
  }

  /* 标定完成后再启动包络滤波和 RMS 滑动窗口，避免静息样本污染有效特征。 */
  Rehab_FirstOrderFilterInit(&emg_envelope_filter, EMG_SENSOR_ENVELOPE_ALPHA, 0.0f);
  Rehab_MovingAverageInit(&emg_rms_average, emg_rms_window, EMG_SENSOR_RMS_WINDOW_LEN);
}

/**
 * @brief 处理单路EMG原始采样数据，更新传感器状态
 * 该函数执行以下操作：
 * 1. 将原始ADC值转换为电压值
 * 2. 若未校准，累积静息样本计算基线均值和噪声方差
 * 3. 若已校准，计算信号相对基线的正向幅值，提取包络线和 RMS
 *    并根据阈值判断激活状态、强度百分比和参与度
 * @param raw 原始ADC采样值
 */
static void EmgSensor_ProcessSample(uint16_t raw)
{
  float signal;
  float strength;
  float rms_mean_square;

  emg_state.raw = raw;
  emg_state.voltage_mv = ((float)raw * EMG_SENSOR_VREF_MV) / EMG_SENSOR_ADC_MAX;

  if (emg_state.calibrated == 0U)
  {
    if (emg_warmup_count < EMG_SENSOR_WARMUP_SAMPLES)
    {
      emg_warmup_count++;
      return;
    }

    /* 标定阶段要求肌肉保持放松，样本只用于建立静息基线和噪声水平。 */
    emg_baseline_sum += raw;
    emg_baseline_square_sum += ((uint64_t)raw * (uint64_t)raw);
    emg_baseline_count++;

    if (emg_baseline_count >= EMG_SENSOR_BASELINE_SAMPLES)
    {
      EmgSensor_FinishBaseline();
    }
    return;
  }

  /* Some EMG front-ends drop voltage during contraction, so use magnitude. */
  signal = fabsf((float)raw - emg_state.baseline);

  emg_state.rectified = signal;
  /* envelope 适合做实时激活判断，RMS 更适合后续做训练窗口特征。 */
  emg_state.envelope = Rehab_FirstOrderFilterUpdate(&emg_envelope_filter, signal);
  rms_mean_square = Rehab_MovingAverageUpdate(&emg_rms_average, signal * signal);
  emg_state.rms = sqrtf(rms_mean_square);
  emg_state.active = (emg_state.envelope >= emg_active_delta) ? 1U : 0U;

  strength = (emg_state.envelope * 100.0f) / emg_full_scale_delta;
  strength = Rehab_ClampFloat(strength, 0.0f, 100.0f);
  emg_state.strength = (uint8_t)(strength + 0.5f);
  /* 当前版本先用强度近似参与度；后续应结合动作有效时间计算参与率。 */
  emg_state.participation = emg_state.strength;
}

/**
 * @brief 处理ADC缓冲区指定区间的数据样本
 * @param start 起始索引
 * @param count 需要处理的样本数量
 */
static void EmgSensor_ProcessRange(uint32_t start, uint32_t count)
{
  uint32_t end = start + count;

  /* 防止错误的 DMA 区间参数越界访问采样缓冲区。 */
  if (end > EMG_SENSOR_BUFFER_LEN)
  {
    return;
  }

  for (uint32_t i = start; i < end; i++)
  {
    EmgSensor_ProcessSample(emg_adc_buffer[i]);
  }
}

/**
 * @brief 启动EMG传感器数据采集
 * 初始化状态变量与缓冲区，启动定时器触发ADC，并开启ADC DMA传输
 * @return HAL_StatusTypeDef HAL_OK表示成功，HAL_ERROR表示失败
 */
HAL_StatusTypeDef EmgSensor_Start(void)
{
  /* 每次启动采集都重新进入静息标定流程。 */
  memset(&emg_state, 0, sizeof(emg_state));
  memset(emg_adc_buffer, 0, sizeof(emg_adc_buffer));
  memset(emg_rms_window, 0, sizeof(emg_rms_window));
  emg_baseline_sum = 0U;
  emg_baseline_square_sum = 0U;
  emg_baseline_count = 0U;
  emg_warmup_count = 0U;

  if (HAL_TIM_Base_Start(&htim3) != HAL_OK)
  {
    return HAL_ERROR;
  }

  return HAL_ADC_Start_DMA(&hadc1,
                           (uint32_t *)emg_adc_buffer,
                           EMG_SENSOR_BUFFER_LEN);
}

/**
 * @brief 处理ADC DMA半传输完成中断对应的数据段
 * 处理缓冲区前半段数据
 */
void EmgSensor_ProcessHalfBuffer(void)
{
  EmgSensor_ProcessRange(0U, EMG_SENSOR_BUFFER_LEN / 2U);
}

/**
 * @brief 处理ADC DMA全传输完成中断对应的数据段
 * 处理缓冲区后半段数据
 */
void EmgSensor_ProcessFullBuffer(void)
{
  EmgSensor_ProcessRange(EMG_SENSOR_BUFFER_LEN / 2U, EMG_SENSOR_BUFFER_LEN / 2U);
}

/**
 * @brief 获取当前EMG传感器状态副本
 * 使用临界段保护，保证状态读取一致性
 * @param state 指向存储状态副本的EmgSensor_State_t结构体指针
 */
void EmgSensor_GetState(EmgSensor_State_t *state)
{
  if (state == NULL)
  {
    return;
  }

  taskENTER_CRITICAL();
  *state = emg_state;
  taskEXIT_CRITICAL();
}
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

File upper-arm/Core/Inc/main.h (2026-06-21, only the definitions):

#define RUN_LED_Pin GPIO_PIN_13
#define RUN_LED_GPIO_Port GPIOC
#define MODE_KEY_Pin GPIO_PIN_0
#define MODE_KEY_GPIO_Port GPIOC
#define DEBUG_TX_Pin GPIO_PIN_0
#define DEBUG_TX_GPIO_Port GPIOA
#define DEBUG_RX_Pin GPIO_PIN_1
#define DEBUG_RX_GPIO_Port GPIOA
#define DATA_TXD_Pin GPIO_PIN_2
#define DATA_TXD_GPIO_Port GPIOA
#define DATA_RXD_Pin GPIO_PIN_3
#define DATA_RXD_GPIO_Port GPIOA
#define IMU_ARM_CS_Pin GPIO_PIN_4
#define IMU_ARM_CS_GPIO_Port GPIOA
#define IMU_ARM_SCK_Pin GPIO_PIN_5
#define IMU_ARM_SCK_GPIO_Port GPIOA
#define IMU_ARM_MISO_Pin GPIO_PIN_6
#define IMU_ARM_MISO_GPIO_Port GPIOA
#define IMU_ARM_MOSI_Pin GPIO_PIN_7
#define IMU_ARM_MOSI_GPIO_Port GPIOA
#define TP_INT_Pin GPIO_PIN_4
#define TP_INT_GPIO_Port GPIOC
#define TP_RST_Pin GPIO_PIN_5
#define TP_RST_GPIO_Port GPIOC
#define EMG_ADC_Pin GPIO_PIN_0
#define EMG_ADC_GPIO_Port GPIOB
#define BUZZER_Pin GPIO_PIN_2
#define BUZZER_GPIO_Port GPIOB
#define LED_STATUS_Pin GPIO_PIN_6
#define LED_STATUS_GPIO_Port GPIOC
#define LCD_BL_Pin GPIO_PIN_8
#define LCD_BL_GPIO_Port GPIOA
#define WIRELESS_RXD_Pin GPIO_PIN_9
#define WIRELESS_RXD_GPIO_Port GPIOA
#define WIRELESS_TXD_Pin GPIO_PIN_10
#define WIRELESS_TXD_GPIO_Port GPIOA
#define VIBRATION_Pin GPIO_PIN_11
#define VIBRATION_GPIO_Port GPIOA
#define USER_KEY_Pin GPIO_PIN_12
#define USER_KEY_GPIO_Port GPIOA
#define LCD_CS_Pin GPIO_PIN_15
#define LCD_CS_GPIO_Port GPIOA
#define LCD_SCL_Pin GPIO_PIN_10
#define LCD_SCL_GPIO_Port GPIOC
#define LCD_SDO_Pin GPIO_PIN_11
#define LCD_SDO_GPIO_Port GPIOC
#define LCD_SDA_Pin GPIO_PIN_12
#define LCD_SDA_GPIO_Port GPIOC
#define TP_SCL_Pin GPIO_PIN_6
#define TP_SCL_GPIO_Port GPIOB
#define TP_SDA_Pin GPIO_PIN_7
#define TP_SDA_GPIO_Port GPIOB
#define LCD_DC_Pin GPIO_PIN_8
#define LCD_DC_GPIO_Port GPIOB
#define LCD_RST_Pin GPIO_PIN_9
#define LCD_RST_GPIO_Port GPIOB
#define VOICE_I2C_SCL_Pin GPIO_PIN_10
#define VOICE_I2C_SCL_GPIO_Port GPIOB
#define VOICE_I2C_SDA_Pin GPIO_PIN_14
#define VOICE_I2C_SDA_GPIO_Port GPIOB

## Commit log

2026-06-08 chore: init repository
    [P183B001-CTP 总成 20241109.dwg]
2026-06-14 feat: 实现腕部节点 IMU 采集与无线遥测
    - 新增 lsm6dsr/imu_processing/wireless_link/emg_sensor 模块
    - SensorTask 做 IMU 采集+零偏校准+姿态解算，WirelessTask 经 USART1 发 24 字节腕部帧
    - 调试串口 USART2(PA2/PA3) 迁移到 UART4(PA0/PA1)，printf 重定向到 huart4
    - LCD 背光改低电平有效、SPI3 改 1LINE/降速；LCD_HEIGHT 284->280
    - ADC EMG 引脚 PC0->PB0 并改 DMA 循环
    - CubeMX 工程 U575.ioc 重命名为 wrist.ioc；内存管理改用 heap_4
2026-06-14 chore: 忽略 IDE 配置与 Keil 调试器临时文件
    - .gitignore 新增 .vscode/、*.dbgconf、*.eprj2 等规则
    - 从跟踪中移除上次误提交的 .vscode/、RTE 调试配置、嵌赛.eprj2（本地保留）
2026-06-14 fix: 调通 CST816T 触摸并增强鲁棒性
    - 触摸坐标 Y 轴翻转对齐显示方向
    - 读失败连续 5 次自动复位 I2C 与芯片，抗干扰自恢复
    - LCD 加 Y offset 修正 240x280 底部偏移
    - 清理触摸 NACK 排查的临时探针/扫描/probe 调试代码
    [lcd_st7789.c, touch_cst816t.c]
2026-06-14 docs: 更新远程地址与协作 Git 流程
    - 远程地址 HZCU-Debug -> woai66
    - 新增协作与 Git 流程小节（分支+PR，不直推 master）
    - 触摸状态更新为已调通（坐标修正 + 失败自恢复）
2026-06-14 docs: 添加 AGENTS.md 代码审查规则
    通用审查偏好（中文、聚焦真 bug、不刷格式、只评论不改代码）+ 可裁剪的嵌入式/RTOS 专属关注项，供 Codex 等自动审查使用。
2026-06-14 feat: 屏上实时显示腕部姿态角
    - LCD 新增 7 段数码管数字绘制 LCD_DrawSeg7Digit / LCD_DrawNumberX10
    - DisplayTask 读共享 wrist_imu_euler，红/绿/蓝三行显示 Roll/Pitch/Yaw（×10 定点，1 位小数）
    - 替换原彩条 + 触摸点测试，跑通 采集→解算→显示 全链路
2026-06-15 fix: 屏显角度保留符号，避免负角显示成近 360°
    显示路径改用带符号的 IMUProc_EulerToSignedX10，归一化到
    [-180,180) 并在零附近做死区，修复 -10° 被显示为 350.0 的问题。
    [app_freertos.c]
2026-06-18 fix: 数码管逐段重绘消除屏显刷新闪烁
    LCD_DrawSeg7Digit 改为对每段直接写最终颜色（亮=color/灭=bg），
    去掉每帧先整块填背景再画段的中间态；符号位、小数点同理。
    依赖首帧已 FillScreen 且数字布局固定，段间隙恒为背景、不再残影。
    [lcd_st7789.c]
2026-06-18 fix: 屏显仅变化时刷新并修正互补滤波增益消除姿态漂移
    - DisplayTask 缓存上帧 roll/pitch/yaw，值不变跳过重绘，静止时不闪。
    - Kp 0.004→1.0、Ki 0.00005→0.05：原增益过小使加速度修正力度
    远小于陀螺零偏，姿态退化为纯积分导致三轴单调漂移；提到合理
    量级后 roll/pitch 收敛锁定，yaw 漂移大幅减小。
    - DebugTask 姿态角 printf 用 DEBUG_ANGLE_PRINT 宏开关，默认关闭。
    [app_freertos.c]
2026-06-19 添加上臂端工程文件
2026-06-19 fix: 按 codex review 修正上臂端多处缺陷
    - USART1 波特率 9600 -> 115200，与腕端发送端及配置一致
    - WirelessTask 接入 USART1 中断接收并调用帧解析器
    - LCD_HEIGHT 284 -> 280，匹配 ST7789V 实际面板
    - LCD 背光改回低电平有效，避免初始化后熄屏
    - 触摸 Y 坐标翻转，对齐 LCD 坐标系
    - emg_rf_model 第 3 类标签 relax -> shake
    - DataStreamTask 恢复 snprintf，消除 len 未初始化读取
    - SensorTask 陀螺日志改为编译开关，默认关闭以免阻塞采样
    [app_freertos.c, lcd_st7789.c, touch_cst816t.c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]
2026-06-21 feat(wrist): 更新无线帧格式并调整 USART1 波特率
    将 WirelessWristFrame_t 字段从四元数/陀螺原始值改为
    acc_mg/gyro_dps_x10/angle_x100/status，帧长从 24 改为 27 字节；
    USART1 波特率从 115200 调整为 9600（匹配 HC-05 默认速率）。
2026-06-21 feat(upper-arm): 接入新无线帧格式并新增康复算法模块
    上臂端 wireless_link 同步 27 字节帧解析（acc_mg/gyro_dps_x10/
    angle_x100/status）；WirelessTask 改为 HC-05 轮询接收（9600 baud）；
    新增 rehab_eval/rehab_model/rehab_training 三个康复算法模块，
    app_freertos 中引入 RehabFrame_t 及完整的 AlgoTask 逻辑。
2026-06-21 feat: 无线帧加回 heart_rate 字段(两端 29 字节)
    新帧重构时删掉了 heart_rate；腕部 mks142 心率仍需发给上臂，
    故在 angle 之后插入 uint16 heart_rate(buf[25..26])，status 移到
    buf[27]，帧长 27->29。腕部 build/上臂 decode 同步，RehabFrame_t
    透传 wrist_heart_rate；status bit1 预留为心率有效位。
    腕部发送端暂填 0，待 feat/heart-rate-mks142 rebase 后接入实际值。
2026-06-21 feat: 腕部接入 MKS142 心率(USART2 逐字节中断收包)
    - 新增 mks142.c/.h 实时包解析(88字节,0xFF头,HR/SpO2/SBP/DBP)
    - HeartRateTask 经 USART2 逐字节中断收包,发布 g_heart_data
    - LCD 增加 LCD_DrawNumberU 整数绘制
    - 修正 SPI3 半双工/分频与 GPDMA 通道配置
    [app_freertos.c, lcd_st7789.c, main.h]
2026-06-21 fix: 按 codex review 修正心率快照/帧同步/超时与构建文档
    - FillWristWirelessFrame 临界区拷心率快照，保证 valid 与 bpm 一致
    - MKS142_FeedByte 帧内遇 0xFF 重新对帧，避免丢字节后错位
    - HeartRateTask 超时清 g_heart_valid，避免无线帧带陈旧 bpm
    - CLAUDE.md 构建命令同步为 wrist.uvprojx -t wrist
    [app_freertos.c]
2026-06-21 feat(upper-arm): restore cached voice and vibration changes
    [app_freertos.c, main.h, upper arm.ioc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]

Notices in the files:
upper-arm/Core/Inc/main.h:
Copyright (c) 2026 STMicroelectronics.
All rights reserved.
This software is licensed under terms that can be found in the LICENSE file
